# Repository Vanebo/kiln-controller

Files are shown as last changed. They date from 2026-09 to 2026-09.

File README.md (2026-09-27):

# Kiln Controller

Open-source ESP32-S3 kiln controller with local controls, a 480 × 320 display, program ramp/hold control, PID regulation, a web interface and browser-based firmware updates.

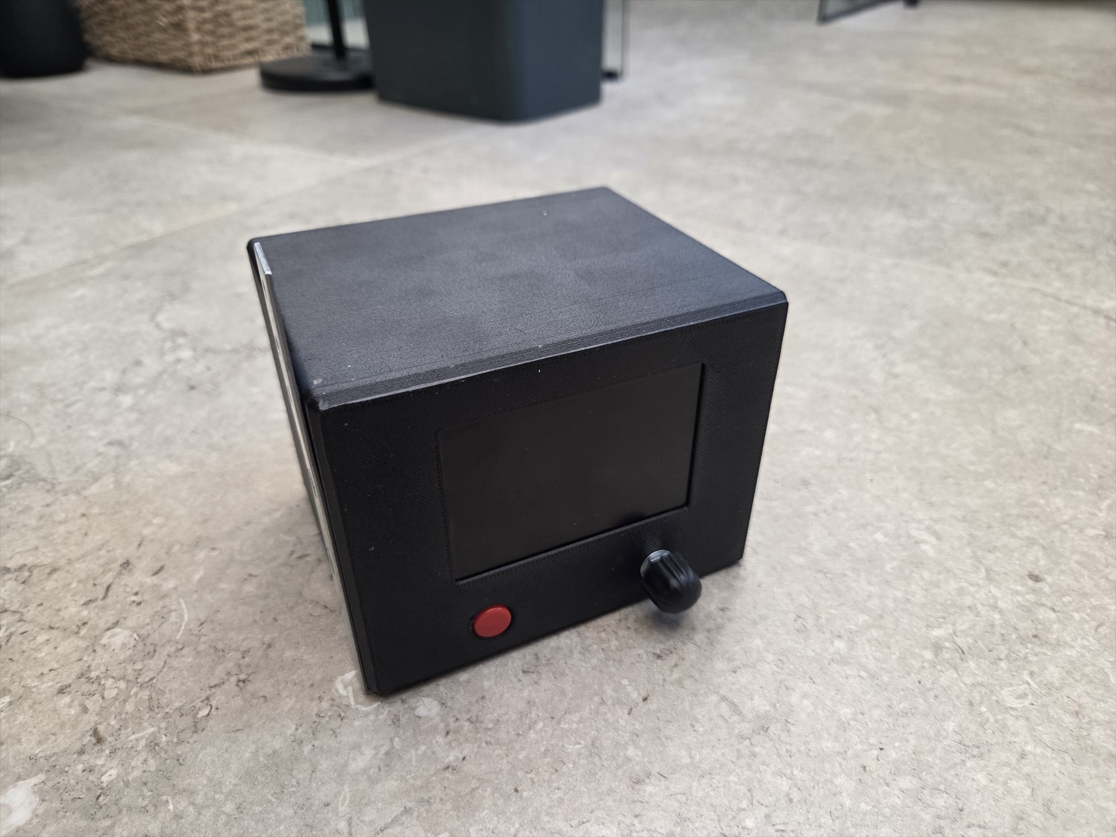
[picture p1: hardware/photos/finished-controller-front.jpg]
Finished kiln controller


The controller output can be adapted to suit electric kilns with different power-control interfaces. The hardware built for this v0.4-series project uses a PWM-to-0–10 V converter: the ESP32 produces a 2 kHz, 12-bit PWM signal on GPIO39, and the external circuit converts it to the 0–10 V command expected by the kiln power regulator. To use another interface—such as a suitably isolated SSR or a different analog standard—replace or adapt the external output stage and update the small hardware-output layer in `src/control.cpp` as required.

> This repository contains controller firmware, not a universal mains-power circuit. Each kiln still needs a correctly rated and suitably isolated power stage, independent over-temperature protection, appropriate fusing and installation by someone qualified for the voltages involved.

## Current version

The imported working project reports firmware **0.4.1** and is the current version on `main`. The project and discussion refer to this generation collectively as v0.4.

## Hardware used by this build

- ESP32-S3 N16R8 development board
- ILI9486 480 × 320 TFT with 8-bit parallel interface
- MAX31855 interface and K-type thermocouple
- Rotary encoder with push button
- Physical STOP/Home button
- External PWM-to-0–10 V output circuit, using either a purchased module or the documented LM358 circuit
- 3D-printed controller housing

The [`hardware documentation`](hardware/README.md) includes the controller connection overview, LM358 PWM-to-0–10 V circuit, finished-product photos and downloadable enclosure models. The completed [`hardware/BOM.md`](hardware/BOM.md) lists the parts, variants and purchase links.

## Pin map

| ESP32-S3 | Connected device |
| --- | --- |
| GPIO1 | Encoder A |
| GPIO2 | Encoder B |
| GPIO4…11 | TFT D0…D7 |
| GPIO12 | TFT RS/DC |
| GPIO13 | TFT WR |
| GPIO14 | TFT RD |
| GPIO15 | TFT CS |
| GPIO16 | TFT reset |
| GPIO17 | MAX31855 CLK |
| GPIO18 | MAX31855 DO |
| GPIO21 | MAX31855 CS |
| GPIO39 | PWM to the 0–10 V interface |
| GPIO40 | Encoder button |
| GPIO42 | Physical STOP/Home button, active low |

GPIO47's onboard RGB LED is intentionally unused.

## Important output setting

The supplied working archive contains this setting in `src/app_config.h`:

```cpp
static constexpr bool ENABLE_REAL_HEATER_OUTPUT = true;
```

This means GPIO39 produces the commanded heater output when the controller is running. Set it to `false` before compiling firmware for display, menu, sensor or web-interface testing where no physical heater command should be generated. Confirm the complete output chain and fail-safe behavior before enabling it again.

`PWM_INVERTED` is `false` in this build. Verify the safe/off state of any replacement output interface; do not assume another power controller uses the same polarity or signal convention.

## Features

- Programmed ramp and hold control with PID.
- Manual temperature mode and protected manual power mode.
- Pause, hold and resume.
- Per-step and global maximum power limits.
- Actual and requested rate-of-rise display.
- Kiln-lag detection and ETA confidence.
- Elapsed and estimated remaining time.
- Nominal duration shown while browsing and starting programs.
- Last five program runs with result and actual elapsed time.
- Live actual-versus-target graph in the web interface.
- Power-failure recovery with explicit Resume/Discard; the heater does not automatically re-energize after reboot.
- Delayed start in 15-minute increments.
- Station Wi-Fi with DHCP and automatic reconnect.
- Setup hotspot started only from the local menu or web settings.
- Browser notifications while the controller page is open.
- Browser-based OTA firmware update.

### v0.4 display improvements

- Partial row redraws reduce flashing during encoder movement.
- Manual temperature, manual power, delayed-start and recovery editors update only the changing field or selection.
- Embedded, pre-rasterized Inter Display-based fonts.
- Larger current temperature and main-screen information.
- Full labels such as **Elapsed** and **Remaining**.
- Nominal program duration based on a 20 °C starting temperature. Live ETA adjusts during firing if the kiln cannot follow the requested ramp.

## Build with PlatformIO

1. Install [Visual Studio Code](https://code.visualstudio.com/) and the [PlatformIO IDE extension](https://platformio.org/install/ide?install=vscode).
2. Clone or download this repository and open its root folder in PlatformIO.
3. Review `src/app_config.h`, especially `ENABLE_REAL_HEATER_OUTPUT` and the pin assignments.
4. Build the `esp32-s3` environment.
5. For initial installation or a changed partition layout, upload over USB.

The PlatformIO configuration targets `esp32-s3-devkitc-1`, 16 MB flash, QIO/OPI memory, LittleFS and the supplied A/B [`partitions.csv`](partitions.csv). PlatformIO installs the declared ArduinoJson and Adafruit MAX31855 dependencies automatically.

The application image is generated at:

```text
.pio/build/esp32-s3/firmware.bin
```

## Browser update from v0.3

v0.3 and v0.4 use the same A/B partition table. If v0.3 is already installed:

1. Build the current firmware in PlatformIO.
2. Open the kiln web interface and make sure the controller is **IDLE**.
3. Open **Settings → System / firmware**.
4. Select `.pio/build/esp32-s3/firmware.bin` and choose **Upload & install**.
5. Do not interrupt power during upload or reboot.
6. Reconnect and verify that the displayed firmware version matches `FIRMWARE_VERSION` in `src/app_config.h`.
7. Confirm that saved programs and settings remain present.

A controller using an older single-application partition layout must be installed over USB once before browser OTA can use the supplied A/B layout.

## Stored data

- Programs: LittleFS `/programs.json`
- Last five runs: LittleFS `/runs.json`
- Power-failure recovery checkpoint: LittleFS `/recovery.json`
- Settings and Wi-Fi credentials: NVS/Preferences

Normal application OTA replaces the inactive application partition and is intended to preserve LittleFS and NVS data.

## Documentation

- [`CHANGELOG.md`](CHANGELOG.md) — reconstructed version history
- [`hardware/BOM.md`](hardware/BOM.md) — parts, variants and purchase links
- [`hardware/README.md`](hardware/README.md) — connection overview, LM358 circuit, photos and enclosure files
- [`hardware/photos/README.md`](hardware/photos/README.md) — finished controller and build gallery
- [`hardware/case/README.md`](hardware/case/README.md) — STL, 3MF and STEP enclosure downloads
- [`docs/LICENSING.md`](docs/LICENSING.md) — license choice and third-party checks
- [`docs/releases/v0.4.1.md`](docs/releases/v0.4.1.md) — current release-note draft

## License

The original project source and documentation are released under the [MIT License](LICENSE), copyright © 2026 Brage (Vanebo). Embedded font data and downloaded build dependencies retain their respective upstream licenses; see [`THIRD_PARTY_NOTICES.md`](THIRD_PARTY_NOTICES.md).

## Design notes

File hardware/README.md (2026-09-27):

# Hardware

This folder documents the working controller build, the optional LM358 output circuit, the printed enclosure and the finished unit. See [`BOM.md`](BOM.md) for the parts list and purchase links.

## Controller connection overview

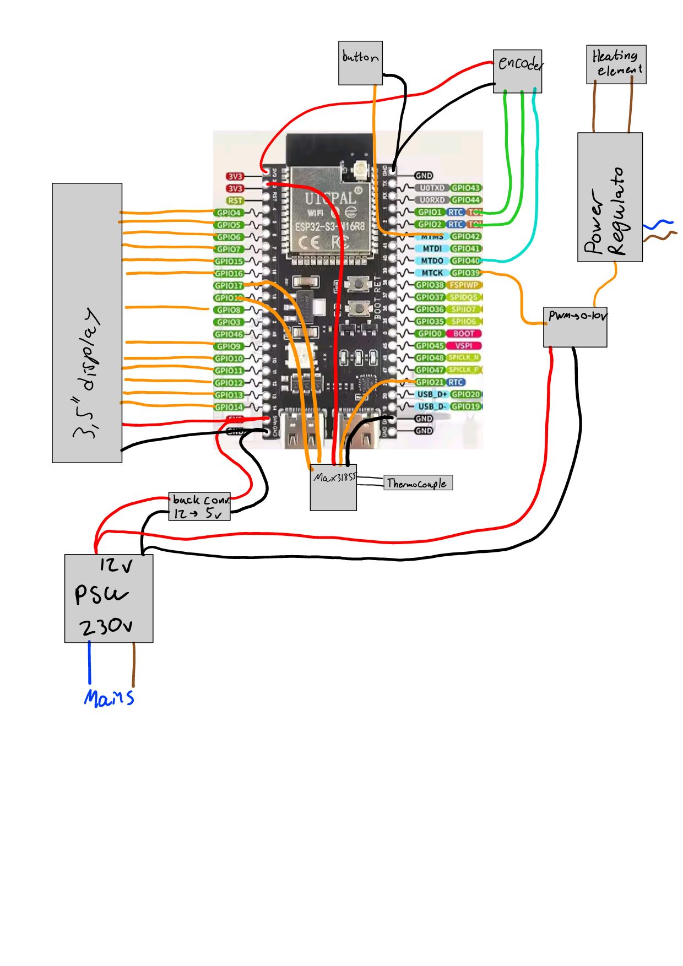
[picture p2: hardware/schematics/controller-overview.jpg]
Controller connection overview


This drawing shows how the display, encoder, stop button, MAX31855 thermocouple interface, power supplies, 0–10 V output and kiln power regulator connect as functional blocks. It is an assembly overview, not a PCB schematic or a complete mains-wiring drawing. Use the firmware pin map in the main [`README.md`](../README.md#pin-map) for the ESP32 connections.

The current build uses:

- a 230 V AC to 12 V DC supply;
- an adjustable buck converter set to the voltage required by the controller electronics;
- a 2 kHz, 12-bit PWM command from ESP32-S3 GPIO39;
- a PWM-to-0–10 V converter; and
- a separate kiln power regulator selected for the kiln supply, phase arrangement and heating-element current.

The mains side, conductor sizes, fusing, earthing, disconnects, over-temperature protection and power-regulator cooling depend on the kiln and installation. They are outside the scope of the overview drawing and must be designed and checked by a qualified person.

## PWM-to-0–10 V output

The purchased PWM-to-voltage module in the [`BOM`](BOM.md) can be replaced by this LM358 circuit:

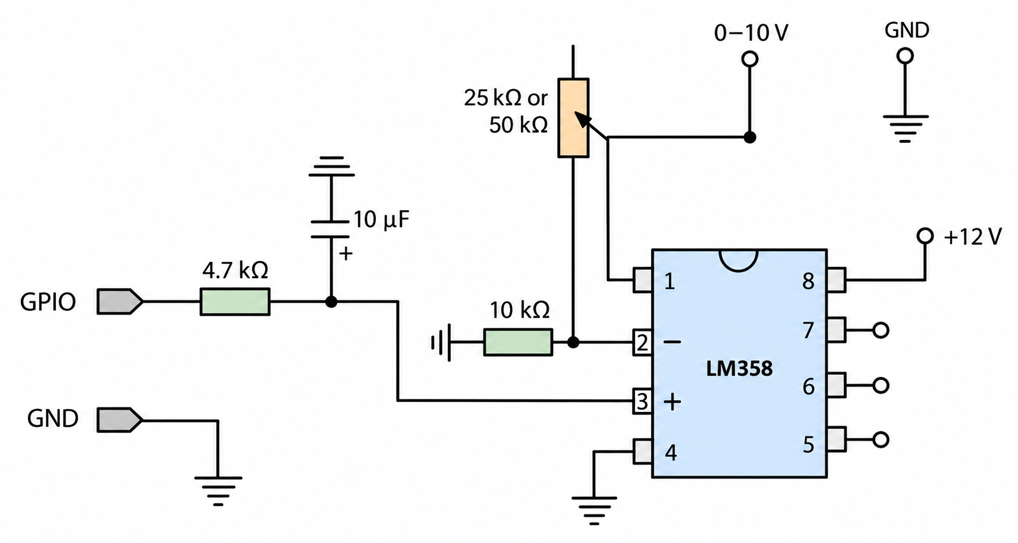
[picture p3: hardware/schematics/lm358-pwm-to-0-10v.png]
LM358 PWM-to-0–10 V circuit


The 4.7 kΩ resistor and 10 µF capacitor low-pass-filter the PWM signal. One half of the LM358 is configured as a non-inverting amplifier. The 10 kΩ resistor and adjustable 25 kΩ or 50 kΩ feedback resistor set the gain so a full-scale PWM command produces 10 V. The LM358 is powered from 12 V.

The drawing focuses on the signal path. Add a 100 nF ceramic bypass capacitor close to LM358 pins 8 and 4. Do not leave the unused amplifier inputs floating: connect pin 5 to ground and connect pin 6 to pin 7 so the second channel operates as a stable follower.

This circuit shares signal ground between the ESP32 side and the 0–10 V input. Confirm that the connected power regulator provides a suitable isolated control input. Add an isolated interface if the kiln hardware requires one.

Before connecting the output to the kiln:

1. Keep the heater output disabled in firmware or disconnect the kiln power regulator.
2. Apply 12 V to the LM358 circuit and confirm the supply polarity.
3. Command 0% output and verify the output is close to 0 V.
4. Command 100% output and adjust the feedback trimmer to 10.00 V.
5. Check several intermediate commands for a stable, approximately linear output.
6. Verify that loss of controller power and a disconnected signal produce the intended safe state.

## Enclosure and 3D files

The printable housing is available in three formats:

- [`kiln-controller-housing.3mf`](case/kiln-controller-housing.3mf) — preferred for slicing;
- [`kiln-controller-housing.stl`](case/kiln-controller-housing.stl) — mesh format; and
- [`kiln-controller-housing.step`](case/kiln-controller-housing.step) — editable solid model.

See the [`case` notes](case/README.md) before printing. Check dimensions and connector clearances against your exact display, buttons, terminals and modules.

## Finished controller and build photos

Finished kiln controller

The full [photo gallery](photos/README.md) includes front and rear views, the MAX31855 module, the output and power boards, and the internal wiring layout.

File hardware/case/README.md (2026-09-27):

# 3D-printed controller housing

The same enclosure is supplied in three formats:

| File | Use |
| --- | --- |
| [`kiln-controller-housing.3mf`](kiln-controller-housing.3mf) | Preferred source for a slicer that supports 3MF |
| [`kiln-controller-housing.stl`](kiln-controller-housing.stl) | Widely compatible triangle mesh |
| [`kiln-controller-housing.step`](kiln-controller-housing.step) | Editable CAD solid for changing openings and mounts |

Verify the imported scale, wall thickness, screw holes, connector openings and clearances before printing. Different suppliers may sell modules with different board dimensions even when the product name is the same. Choose print material and placement for the temperature expected at the controller's installed location.

The photos in [`../photos`](../photos/README.md) show the completed housing and component layout used for the documented build.

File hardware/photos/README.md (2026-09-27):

# Build photos

## Finished controller

| Front | Rear |
| --- | --- |
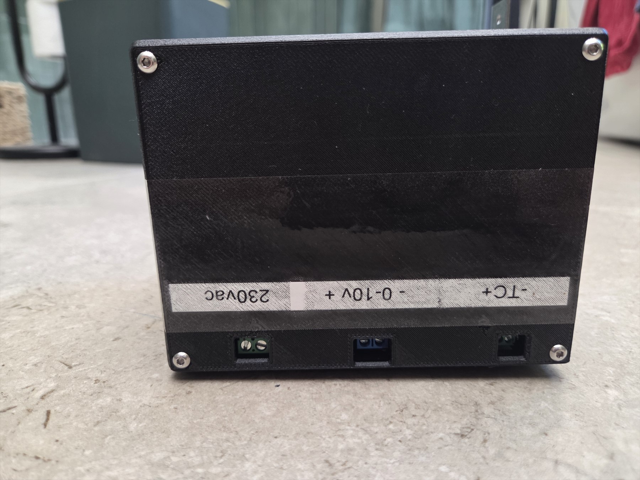
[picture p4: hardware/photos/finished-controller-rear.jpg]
Finished controller, rear
| Finished controller, front |  |

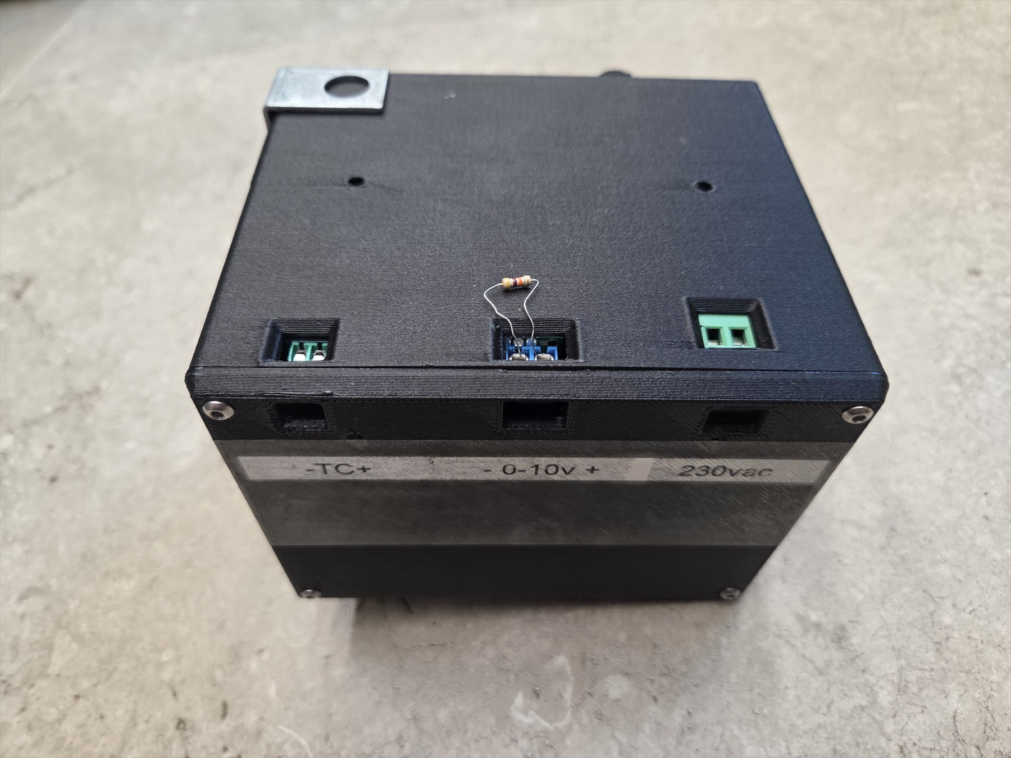
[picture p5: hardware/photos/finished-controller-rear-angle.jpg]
Finished controller, rear angle


## Internal assembly

| Enclosure layout | Internal wiring |
| --- | --- |
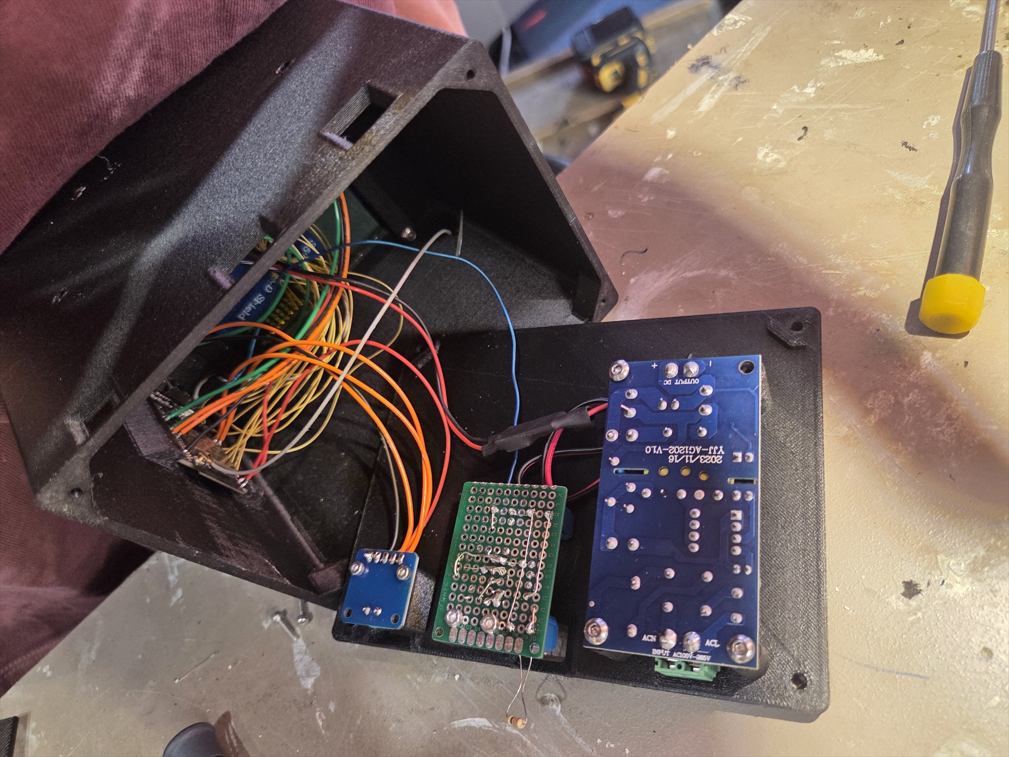
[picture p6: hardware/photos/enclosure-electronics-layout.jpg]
Electronics laid out in the enclosure
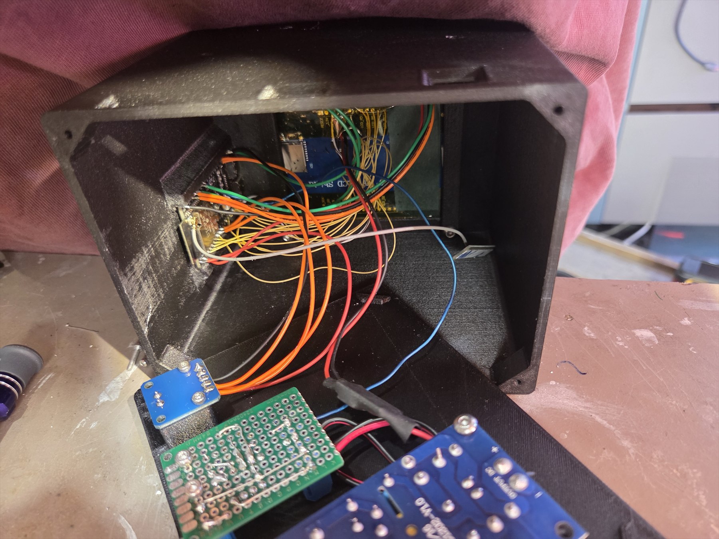
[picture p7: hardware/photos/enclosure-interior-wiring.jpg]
Wiring inside the enclosure
|  |  |

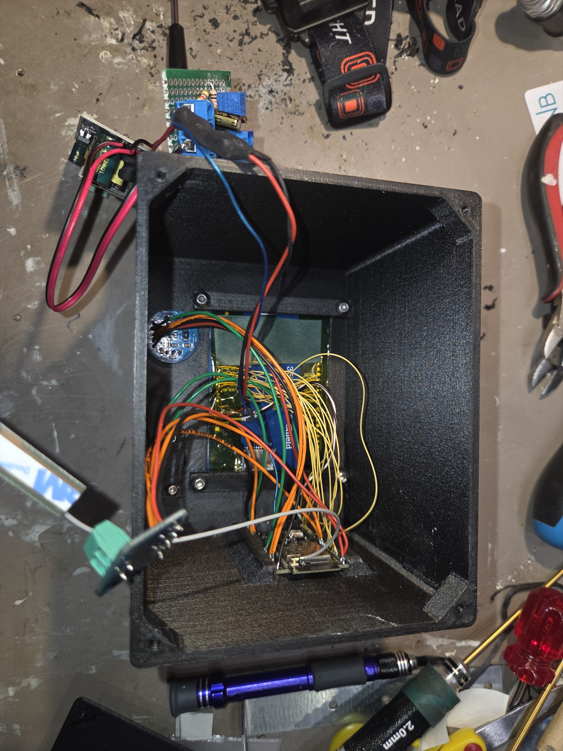
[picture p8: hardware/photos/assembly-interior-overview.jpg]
Controller assembly overview


## Modules and output boards

| MAX31855 interface | Output and power boards |
| --- | --- |
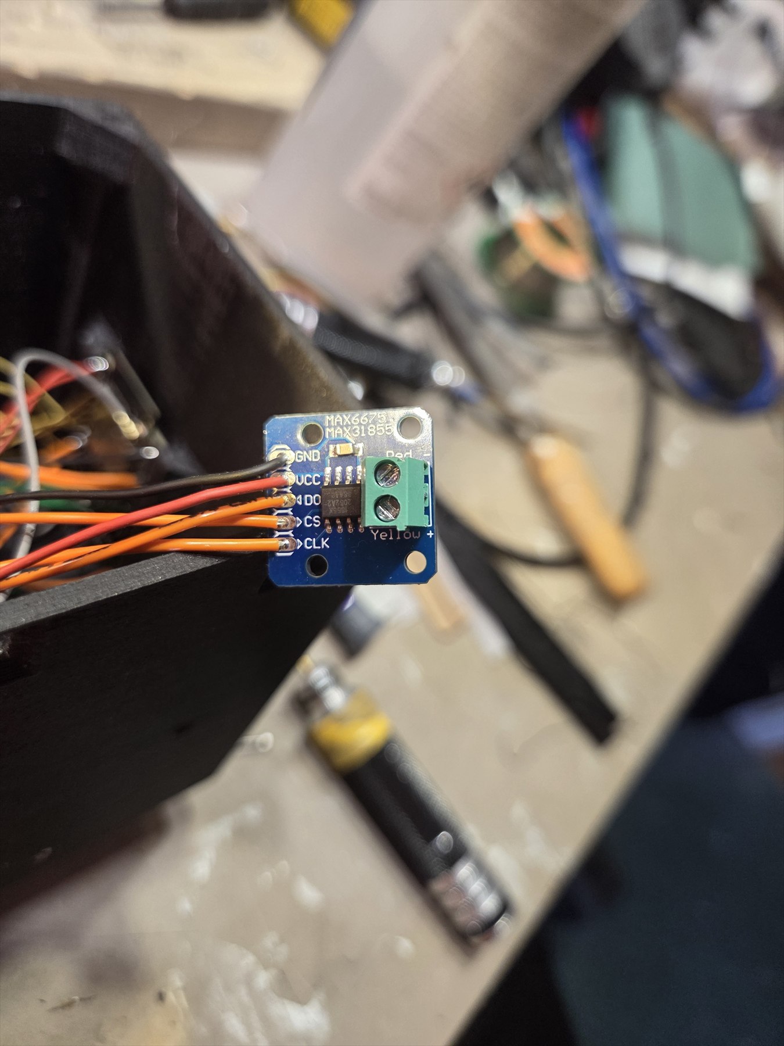
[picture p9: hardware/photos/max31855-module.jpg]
MAX31855 thermocouple interface
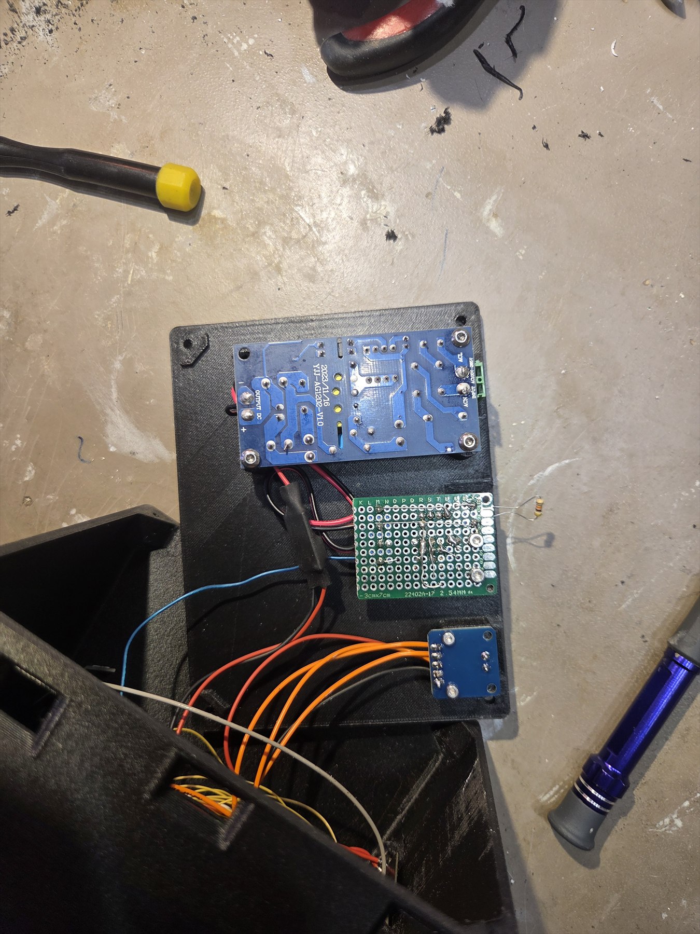
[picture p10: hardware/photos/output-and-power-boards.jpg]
PWM converter and power-supply boards
|  |  |

These photos document the prototype that was used to develop the firmware. Use the connection overview and pin map for wiring; photographs alone are not a substitute for checking every connection.

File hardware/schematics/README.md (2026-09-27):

# Schematics and connection drawings

- [`controller-overview.jpg`](controller-overview.jpg) shows how the controller modules connect as functional blocks. It is not a complete mains-wiring diagram.
- [`lm358-pwm-to-0-10v.png`](lm358-pwm-to-0-10v.png) shows the optional LM358 circuit that can replace the purchased PWM-to-voltage module.

Read the explanations, implementation notes and calibration procedure in the main [`hardware` documentation](../README.md).

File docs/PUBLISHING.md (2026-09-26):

# Publication preparation

## Current status

- GitHub profile access confirmed for `Vanebo`.
- The supplied `kiln_PIDcontroller_v04.zip` working project was imported without generated `.pio` output or editor metadata.
- The imported firmware identifies itself as 0.4.1 and has real heater output enabled.
- The accessible conversation and project documentation provide only partial v0.1–v0.3 history.
- A clean PlatformIO release build completed successfully on 2026-09-26. Hardware and OTA behavior were not retested during publication preparation.
- MIT licensing was selected for the original project source and documentation. The Inter-based embedded font attribution is recorded separately.
- The public `Vanebo/kiln-controller` repository was created and the reviewed source was published to `main` on 2026-09-26.
- The v0.4.1 release is prepared; its firmware asset and final release publication remain pending.

## Imported working version

The original ZIP remains outside this repository. The PlatformIO configuration, partition table and top-level files from `src/` were copied into the public repository structure. Generated build files, downloaded dependencies, `.vscode` state and `.qodo` metadata were excluded.

Before publishing, inspect source and assets for credentials or personal runtime data. Keep required defaults and sample programs; exclude real credentials, filesystem dumps and build caches. Document any necessary redaction instead of silently changing firmware behavior.

The README now records the board, display, sensor, pin assignments, 0–10 V control path, initial build/upload process and storage layout. Add the owner's schematic and BOM links before declaring the hardware documentation complete.

## Version history

Import v0.4 as the `main` version. Keep v0.1–v0.3 history in the changelog unless authentic earlier snapshots become available. Never tag the v0.4 commit as older firmware. If older archives arrive, establish their exact contents and versions before creating historical tags or releases.

## Publish

After importing and reviewing the source, use the chosen GitHub repository. If it already exists, inspect its contents and preserve its history. Commit the complete reviewed project to `main`; do not overwrite unrelated work.

The `esp32-s3` environment builds successfully with Espressif32 platform 7.1.3, Arduino-ESP32 framework package 4.20017.260907, ArduinoJson 6.21.6 and Adafruit MAX31855 1.4.2. The build used 92,456 bytes of RAM (28.2%) and 971,497 bytes of application flash (15.4% of the 6,291,456-byte app partition). Test the resulting firmware on the target hardware before claiming hardware or OTA validation.

Create tag `v0.4.1` only at the commit containing this imported working firmware. Use `docs/releases/v0.4.1.md` as the release body after updating its verification status. Attach a verified application image only if built from that tagged commit; include its checksum and board/build configuration. GitHub's source archive is not a precompiled firmware image.

Do not publish the placeholder historical notes as actual releases until their corresponding source and history are recovered.

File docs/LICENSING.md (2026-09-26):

# Licensing

The original Kiln Controller source and documentation are released under the [MIT License](../LICENSE):

```text
Copyright (c) 2026 Brage (Vanebo)
```

The MIT license permits use, copying, modification, distribution, sublicensing and sale, provided that its copyright and permission notice remain with copies or substantial portions of the software.

Third-party material retains its own license. In particular, the embedded Inter-based font data is covered by the SIL Open Font License 1.1; see [`THIRD_PARTY_NOTICES.md`](../THIRD_PARTY_NOTICES.md). PlatformIO dependencies also retain their upstream licenses.

Future schematic images or other contributed assets should state their license if it differs from MIT.

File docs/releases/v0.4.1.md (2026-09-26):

# Kiln Controller v0.4.1

Release-note draft for the supplied working v0.4-series firmware.

This release contains the current ESP32-S3 kiln controller with local display and encoder controls, PID ramp/hold programs, a responsive web interface and browser-based OTA updates.

The v0.4 interface improves readability and responsiveness with partial screen redraws, embedded smoother fonts, larger temperature and dashboard text, full **Elapsed** and **Remaining** labels, and planned program duration in the local and web program browsers.

The hardware used for this build converts the 2 kHz, 12-bit PWM signal on GPIO39 to a 0–10 V command for the kiln power regulator. The output stage can be replaced or adapted for other electric-kiln control interfaces. Builders must use correctly rated and suitably isolated hardware for their kiln.

The supplied working source has `ENABLE_REAL_HEATER_OUTPUT = true`. Set it to `false` for dry testing without a physical heater command, and verify the complete control chain before enabling real output.

For OTA from v0.3, build the `esp32-s3` environment and upload `.pio/build/esp32-s3/firmware.bin` through **Settings → System / firmware** while the kiln is idle. After reboot, verify firmware **0.4.1** and confirm that saved programs and settings remain available.

Verification: a clean PlatformIO release build completed successfully on 2026-09-26. It used 92,456 bytes of RAM and 971,497 bytes of application flash. Hardware and OTA behavior were not retested as part of repository preparation.

Release binary SHA-256:

```text
C140E6DBB3F1F97B84CF770998AA642960F439056764CC95F63382D3E5ACE6ED  kiln-controller-v0.4.1-esp32-s3.bin
```

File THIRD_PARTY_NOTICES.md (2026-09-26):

# Third-party notices

## Inter font

The rasterized glyph data in `src/ui_fonts.h` is based on the Inter typeface.

Inter is copyright © 2016 The Inter Project Authors and is distributed under the SIL Open Font License, Version 1.1. The license permits the font to be bundled and embedded with software subject to its conditions. See the [Inter license and copyright notice](https://github.com/rsms/inter/blob/master/LICENSE.txt).

The original font files are not included in this repository; the firmware contains pre-rasterized glyph data generated from the font.

## PlatformIO dependencies

PlatformIO obtains ArduinoJson, Adafruit MAX31855 and their dependencies during the build. Those packages remain under their respective upstream licenses. See the versions resolved by PlatformIO and the license files installed with each dependency.

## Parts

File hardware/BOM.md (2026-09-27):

# Bill of materials

These are the parts used for the current 0–10 V build. Some purchase links below are affiliate links. The project author may receive a commission if you buy through them, at no additional cost to you.

AliExpress listings and option names can change. Check the voltage, interface, board shape and selected variant before ordering. Equivalent parts can be used when their electrical specifications and pinout match the firmware and schematic.

| Qty | Part | Manufacturer / model / value | Purchase link | Notes |
| ---: | --- | --- | --- | --- |
| 1 | Microcontroller board | ESP32-S3 development board, N16R8, USB-C, external 2.4 GHz antenna connection | [AliExpress](https://s.click.aliexpress.com/e/_c4V1haxx) | Choose the ESP32-S3 N16R8 version used by this firmware and confirm its pinout matches the wiring diagram. |
| 1 | Rotary encoder module | EC11 rotary encoder breakout with push switch and knob cap | [AliExpress](https://s.click.aliexpress.com/e/_c38xIEVJ) | The listing title advertises a two-piece pack; only one encoder module is required for the controller. |
| 1 | TFT display | 3.5-inch 480×320 TFT LCD; select the **without touch** option | [AliExpress](https://s.click.aliexpress.com/e/_c3VFtWav) | Confirm an ILI9486-compatible controller and 8-bit parallel interface before ordering. |
| 1 | Thermocouple interface | **Square** MAX31855 module for a K-type thermocouple | [AliExpress](https://s.click.aliexpress.com/e/_c32PNhKz) | Select the square-board version. The listing advertises measurement to 800 °C; use a thermocouple and interface rated for the highest intended kiln temperature. |
| 1 | Analog output converter | PWM-to-voltage converter with 0–10 V output | [AliExpress](https://s.click.aliexpress.com/e/_c3F7v1zb) | Confirm the selected board converts PWM **to** 0–10 V; the listing title is ambiguous about signal direction. Calibrate the output before connecting it to the kiln. |
| 1 | Kiln power regulator | LCTC AC voltage-regulator module; single-phase 220/380 V and three-phase 380 V variants are available | [AliExpress](https://s.click.aliexpress.com/e/_c3RMyyzB) | Select the phase and voltage for the kiln. The required current rating depends on the heating elements; calculate their full-load current and provide suitable margin, cooling and circuit protection. |
| 1 | Low-voltage power supply | AC-to-DC switching supply module, **12 V 2 A, 24 W** option | [AliExpress](https://s.click.aliexpress.com/e/_c3tpCyiv) | This is a bare mains-voltage module. Install it in a suitable enclosed, insulated assembly with appropriate input protection and strain relief; have mains wiring completed and checked by a qualified person. |
| 1 | DC step-down converter | MP1584EN adjustable buck-converter module, rated up to 3 A | [AliExpress](https://s.click.aliexpress.com/e/_c3l9w9nR) | The listing advertises a five-piece pack; only one module is required. Adjust and measure its output voltage before connecting the controller electronics. |
| 1 | Kiln thermocouple | K-type high-temperature probe rated to 1300 °C; 150, 200 and 250 mm options | [AliExpress](https://s.click.aliexpress.com/e/_c4rd7vdF) | Select the probe length to suit the kiln and installation setup. Confirm the probe diameter, connector and lead arrangement before ordering. |

## Optional LM358 PWM-to-0–10 V circuit

Use these parts in place of the purchased analog output converter. See the [circuit and calibration instructions](README.md#pwm-to-010-v-output).

| Qty | Part | Value | Notes |
| ---: | --- | --- | --- |
| 1 | Dual operational amplifier | LM358 | One amplifier channel is used; powered from 12 V. |
| 1 | Input resistor | 4.7 kΩ | Forms the PWM low-pass filter. |
| 1 | Filter capacitor | 10 µF | Observe electrolytic polarity as shown in the circuit. |
| 1 | Supply bypass capacitor | 100 nF ceramic | Fit close to LM358 pins 8 and 4. |
| 1 | Gain resistor | 10 kΩ | From the inverting input to ground. |
| 1 | Adjustable feedback resistor | 25 kΩ or 50 kΩ trimmer | Adjust for 10.00 V at a 100% PWM command. |
| 1 | Prototype board or PCB | As required | Keep low-voltage signal wiring separate from mains wiring. |

The controller firmware outputs a 2 kHz, 12-bit PWM signal on GPIO39. The present hardware converts this to 0–10 V. To use another electric kiln, replace or adapt the output interface for the kiln's required control signal and update the firmware configuration as needed. Do not connect an ESP32 pin directly to a kiln control or mains circuit.

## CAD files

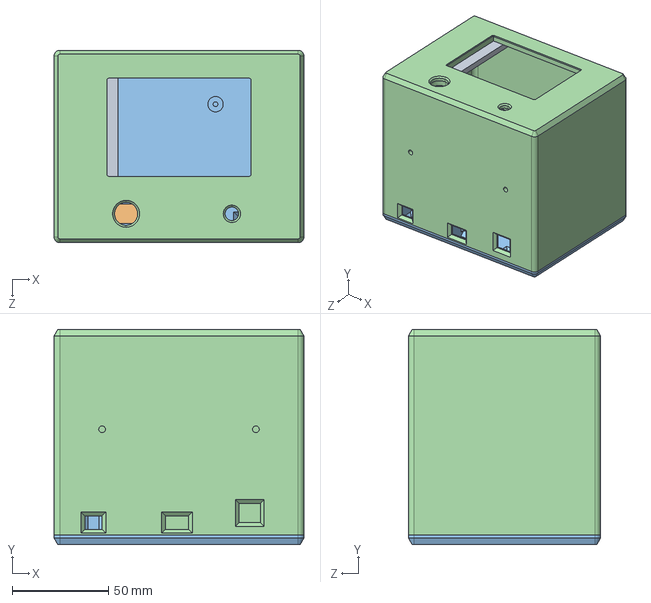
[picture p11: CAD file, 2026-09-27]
hardware/case/kiln-controller-housing.step
130.0 x 112.0 x 100.0 mm

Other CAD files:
hardware/case/kiln-controller-housing.3mf
hardware/case/kiln-controller-housing.stl

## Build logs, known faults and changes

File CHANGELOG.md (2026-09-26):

# Changelog

This history was reconstructed from the supplied working v0.4 project and the accessible development conversation. The source snapshots and full discussion for the earliest releases are not available, so uncertain details remain clearly marked.

## 0.4.1

The supplied working v0.4 project identifies itself as `0.4.1`. The accessible discussion does not describe the exact change from 0.4.0 to 0.4.1. In this source, real heater output is enabled and configured for a PWM-to-0–10 V interface.

## 0.4.0

### Added

- Embedded, smoother Inter Display-based fonts.
- Nominal program duration in the local program browser, program start screen and web program cards.

### Changed

- Encoder menus use partial row updates to reduce full-screen flashing.
- Manual temperature, manual power, delayed-start and recovery screens update only the changing areas.
- Increased the size of current-temperature and secondary dashboard text.
- Replaced abbreviated timing labels with **Elapsed** and **Remaining**.

## 0.3

The later project documentation confirms that v0.3 included the browser firmware-update interface and used the same A/B partition table as v0.4. A complete version-specific change list is not available.

## 0.2

The supplied project documentation says the A/B partition layout was present by v0.2. The remaining v0.2 changes are not available in the accessible history.

## 0.1

Initial historical version. Its exact feature set and source snapshot are not available, so no unverified changes have been attributed to it.

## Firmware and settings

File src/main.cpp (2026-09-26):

#include <Arduino.h>
#include "app_config.h"
#include "app_state.h"
#include "storage.h"
#include "control.h"
#include "input.h"
#include "display_ui.h"
#include "network.h"
#include "web_server.h"

void setup() {
  Serial.begin(115200);
  delay(1200);

  Serial.println();
  Serial.println("========================================");
  Serial.print("Kiln Controller v");
  Serial.println(FIRMWARE_VERSION);
  Serial.println(SIMULATION_MODE ? "SIMULATION MODE" : "REAL SENSOR MODE");
  Serial.println(ENABLE_REAL_HEATER_OUTPUT ? "REAL HEATER OUTPUT ENABLED" : "REAL HEATER OUTPUT DISABLED");
  Serial.println("========================================");

  initStorage();
  loadSettingsFromStorage();
  loadPrograms();
  loadRunLog();
  loadRecoverySnapshot();

  if (recovery.available) {
    Serial.println(String("Interrupted firing found: ") + recovery.programName);
    Serial.println("Heater remains OFF until the user explicitly resumes or discards it.");
  }

  initControlHardware();
  initInput();
  initLocalUi();
  initNetwork();
  initWebServer();

  lastHistoryMs = millis() - HISTORY_INTERVAL_MS;
  lastRateSampleMs = millis() - RATE_SAMPLE_INTERVAL_MS;
}

void loop() {
  handleWebServer();
  updateNetwork();
  updateLocalUi();

  updateTemperature();
  updateRateOfRise();
  updateProfileAndDelay();
  updateControlOutput();
  checkSafety();
  updateLagDetection();
  addHistorySample();

  if (millis() - lastDisplayMs >= 500) {
    lastDisplayMs = millis();
    refreshMainDisplay(false);
  }

  delay(2);
}

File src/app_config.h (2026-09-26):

#pragma once
#include <Arduino.h>

// ============================================================
// BUILD / SAFETY SWITCHES
// ============================================================
static constexpr const char *FIRMWARE_VERSION = "0.4.1";

// Use the real MAX31855 by default.
static constexpr bool SIMULATION_MODE = false;

// IMPORTANT: leave false until the PWM -> 0-10 V chain has been verified.
static constexpr bool ENABLE_REAL_HEATER_OUTPUT = true;
static constexpr bool PWM_INVERTED = false;

// ============================================================
// PIN MAP
// ============================================================
// ILI9486, 8-bit parallel
static constexpr uint8_t TFT_D0 = 4;
static constexpr uint8_t TFT_D1 = 5;
static constexpr uint8_t TFT_D2 = 6;
static constexpr uint8_t TFT_D3 = 7;
static constexpr uint8_t TFT_D4 = 8;
static constexpr uint8_t TFT_D5 = 9;
static constexpr uint8_t TFT_D6 = 10;
static constexpr uint8_t TFT_D7 = 11;
static constexpr uint8_t TFT_RS = 12;
static constexpr uint8_t TFT_WR = 13;
static constexpr uint8_t TFT_RD = 14;
static constexpr uint8_t TFT_CS = 15;
static constexpr uint8_t TFT_RST = 16;

// MAX31855
static constexpr uint8_t TC_CLK = 17;
static constexpr uint8_t TC_DO  = 18;
static constexpr uint8_t TC_CS  = 21;

// Rotary encoder
static constexpr uint8_t ENC_A = 1;
static constexpr uint8_t ENC_B = 2;
static constexpr uint8_t ENC_BTN = 40;
static constexpr int ENCODER_TRANSITIONS_PER_DETENT = 4;

// Heater output / physical STOP
static constexpr uint8_t HEATER_PWM_PIN = 39;
static constexpr uint8_t STOP_PIN = 42; // active LOW

// ============================================================
// DISPLAY
// ============================================================
static constexpr int LCD_WIDTH = 480;
static constexpr int LCD_HEIGHT = 320;

static constexpr uint16_t BLACK    = 0x0000;
static constexpr uint16_t WHITE    = 0xFFFF;
static constexpr uint16_t CYAN     = 0x07FF;
static constexpr uint16_t BLUE     = 0x001F;
static constexpr uint16_t DARKGREY = 0x4208;
static constexpr uint16_t MIDGREY  = 0x8410;
static constexpr uint16_t GREEN    = 0x07E0;
static constexpr uint16_t YELLOW   = 0xFFE0;
static constexpr uint16_t RED      = 0xF800;

// ============================================================
// PWM
// ============================================================
static constexpr uint8_t PWM_CHANNEL = 0;
static constexpr uint16_t PWM_FREQ = 2000;
static constexpr uint8_t PWM_BITS = 12;
static constexpr uint16_t PWM_MAX = (1u << PWM_BITS) - 1;

// ============================================================
// LIMITS / TIMINGS
// ============================================================
static constexpr size_t MAX_PROGRAMS = 12;
static constexpr size_t MAX_STEPS = 12;
static constexpr size_t HISTORY_SIZE = 2048; // 30 sec/sample ~= 17 h
static constexpr size_t RUN_LOG_SIZE = 5;
static constexpr size_t RATE_BUFFER_SIZE = 75; // ~75 seconds at 1 Hz

static constexpr uint32_t HISTORY_INTERVAL_MS = 30000UL;
static constexpr uint32_t RATE_SAMPLE_INTERVAL_MS = 1000UL;
static constexpr uint32_t RECOVERY_SAVE_INTERVAL_MS = 60000UL;
static constexpr uint32_t WIFI_RETRY_INTERVAL_MS = 15000UL;
static constexpr uint32_t AP_TIMEOUT_MS = 10UL * 60UL * 1000UL;
static constexpr uint16_t DELAY_INCREMENT_MIN = 15;
static constexpr uint16_t MAX_DELAY_MIN = 48 * 60;

// Lag detection is intentionally conservative.
static constexpr float LAG_TEMP_ERROR_C = 15.0f;
static constexpr float LAG_RATE_RATIO = 0.75f;
static constexpr uint32_t LAG_CONFIRM_MS = 60000UL;

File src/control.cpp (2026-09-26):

#include "control.h"
#include "app_config.h"
#include "storage.h"
#include <Adafruit_MAX31855.h>
#include <math.h>

static Adafruit_MAX31855 thermocouple(TC_CLK, TC_CS, TC_DO);

static void writePhysicalOutput(float pct) {
  pct = constrain(pct, 0.0f, 100.0f);
  float physical = ENABLE_REAL_HEATER_OUTPUT ? pct : 0.0f;
  uint32_t duty = (uint32_t)roundf(physical * PWM_MAX / 100.0f);
  if (PWM_INVERTED) duty = PWM_MAX - duty;
  ledcWrite(PWM_CHANNEL, duty);
}

static void resetPid() {
  pidIntegral = 0.0f;
  pidLastError = 0.0f;
  pidLastMs = millis();
}

static bool sensorReadyForHeat() {
  if (SIMULATION_MODE) return true;
  return thermocoupleValid && currentTemp < settings.maxTemp;
}

static uint32_t currentProgramElapsedSec() {
  return elapsedRunSeconds();
}

static void resetRunStateToIdle() {
  runMode = RunMode::IDLE;
  activeProgram = -1;
  activeStep = -1;
  pendingProgram = -1;
  pendingDelayMin = 0;
  delayedStartAtMs = 0;
  programPaused = false;
  heaterPower = 0.0f;
  faultMessage = "";
  runStartMs = 0;
  resetPid();
  writePhysicalOutput(0);
}

static void finishProgram(RunResult result, const String &eventType) {
  String name = (activeProgram >= 0 && activeProgram < (int)programCount)
                  ? programs[activeProgram].name : String("Program");
  uint32_t elapsed = currentProgramElapsedSec();
  appendRunRecord(name, result, elapsed);
  clearRecoverySnapshot();
  emitEvent(eventType, name + " - " + resultName(result));
  resetRunStateToIdle();
}

static void advanceStep() {
  activeStep++;
  if (activeProgram < 0 || activeStep >= programs[activeProgram].stepCount) {
    finishProgram(RunResult::COMPLETED, "complete");
    return;
  }
  programPhase = ProgramPhase::RAMP;
  resumePhase = ProgramPhase::RAMP;
  phaseStartMs = millis();
  phaseStartTarget = targetTemp;
  saveRecoverySnapshot(true);
}

void initControlHardware() {
  pinMode(STOP_PIN, INPUT_PULLUP);
  ledcSetup(PWM_CHANNEL, PWM_FREQ, PWM_BITS);
  ledcAttachPin(HEATER_PWM_PIN, PWM_CHANNEL);
  writePhysicalOutput(0);
  pidLastMs = millis();
  simLastMs = millis();
}

bool startProgramNow(int index) {
  if (runMode != RunMode::IDLE) return false;
  if (recovery.available) return false;
  if (index < 0 || index >= (int)programCount) return false;
  if (!sensorReadyForHeat()) return false;

  activeProgram = index;
  activeStep = 0;
  runMode = RunMode::PROGRAM;
  programPhase = ProgramPhase::RAMP;
  resumePhase = ProgramPhase::RAMP;
  programPaused = false;
  phaseStartMs = millis();
  phaseStartTarget = currentTemp;
  targetTemp = currentTemp;
  runStartMs = millis();
  faultMessage = "";
  resetPid();
  clearRecoverySnapshot();
  saveRecoverySnapshot(true);
  emitEvent("start", programs[index].name + " started");
  return true;
}

bool scheduleDelayedProgram(int index, uint16_t delayMinutes) {
  if (runMode != RunMode::IDLE || recovery.available) return false;
  if (index < 0 || index >= (int)programCount) return false;
  if (delayMinutes == 0) return startProgramNow(index);
  delayMinutes = constrain((int)delayMinutes, (int)DELAY_INCREMENT_MIN, (int)MAX_DELAY_MIN);
  delayMinutes = (delayMinutes / DELAY_INCREMENT_MIN) * DELAY_INCREMENT_MIN;
  pendingProgram = index;
  pendingDelayMin = delayMinutes;
  delayedStartAtMs = millis() + (uint32_t)delayMinutes * 60000UL;
  runMode = RunMode::DELAYED_START;
  heaterPower = 0.0f;
  writePhysicalOutput(0);
  emitEvent("delay", programs[index].name + " scheduled in " + String(delayMinutes) + " min");
  return true;
}

void cancelDelayedStart() {
  if (runMode != RunMode::DELAYED_START) return;
  emitEvent("cancel", "Delayed start cancelled");
  resetRunStateToIdle();
}

bool startManualTemp(float temp) {
  if (runMode != RunMode::IDLE || recovery.available) return false;
  if (!sensorReadyForHeat()) return false;
  if (temp < 0 || temp > settings.maxTemp) return false;
  manualTarget = temp;
  targetTemp = temp;
  runMode = RunMode::MANUAL_TEMP;
  runStartMs = millis();
  faultMessage = "";
  resetPid();
  emitEvent("start", "Manual temperature started");
  return true;
}

bool startManualPower(float power) {
  if (runMode != RunMode::IDLE || recovery.available) return false;
  if (!sensorReadyForHeat()) return false;
  if (currentTemp >= settings.manualPowerTempLimit) return false;
  manualPowerRequest = constrain(power, 0.0f, settings.manualPowerMax);
  runMode = RunMode::MANUAL_POWER;
  manualPowerStartMs = millis();
  runStartMs = millis();
  faultMessage = "";
  resetPid();
  emitEvent("start", "Manual power started");
  return true;
}

bool pauseProgram() {
  if (runMode != RunMode::PROGRAM || programPaused) return false;
  programPaused = true;
  resumePhase = programPhase;
  pauseStartMs = millis();
  pausedTarget = currentTemp;
  targetTemp = pausedTarget;
  resetPid();
  saveRecoverySnapshot(true);
  emitEvent("pause", programs[activeProgram].name + " paused");
  return true;
}

bool resumeProgram() {
  if (runMode != RunMode::PROGRAM || !programPaused) return false;
  uint32_t pausedFor = millis() - pauseStartMs;
  phaseStartMs += pausedFor;
  programPhase = resumePhase;
  programPaused = false;
  resetPid();
  saveRecoverySnapshot(true);
  emitEvent("resume", programs[activeProgram].name + " resumed");
  return true;
}

void stopControlByUser() {
  if (runMode == RunMode::PROGRAM && activeProgram >= 0) {
    finishProgram(RunResult::ABORTED, "aborted");
    return;
  }
  if (runMode == RunMode::DELAYED_START) {
    cancelDelayedStart();
    return;
  }
  if (runMode == RunMode::MANUAL_TEMP || runMode == RunMode::MANUAL_POWER) {
    emitEvent("stopped", "Manual mode stopped");
  }
  resetRunStateToIdle();
}

void tripFault(const String &message) {
  if (runMode == RunMode::FAULT && faultMessage == message) return;

  if (runMode == RunMode::PROGRAM && activeProgram >= 0) {
    String name = programs[activeProgram].name;
    appendRunRecord(name, RunResult::FAULTED, currentProgramElapsedSec());
    clearRecoverySnapshot();
  }

  faultMessage = message;
  runMode = RunMode::FAULT;
  programPaused = false;
  heaterPower = 0.0f;
  writePhysicalOutput(0);
  emitEvent("fault", message);
}

bool clearFault() {
  if (runMode != RunMode::FAULT) return false;
  if (!sensorReadyForHeat()) return false;
  resetRunStateToIdle();
  emitEvent("fault-clear", "Fault cleared");
  return true;
}
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

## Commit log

2026-09-26 Publish kiln controller v0.4.1 source
    [partitions.csv]
2026-09-26 Document kiln controller bill of materials
2026-09-26 Add kiln regulator and thermocouple to BOM
2026-09-27 Add hardware schematics, photos, and enclosure models
    [kiln-controller-housing.3mf, kiln-controller-housing.step, kiln-controller-housing.stl]
